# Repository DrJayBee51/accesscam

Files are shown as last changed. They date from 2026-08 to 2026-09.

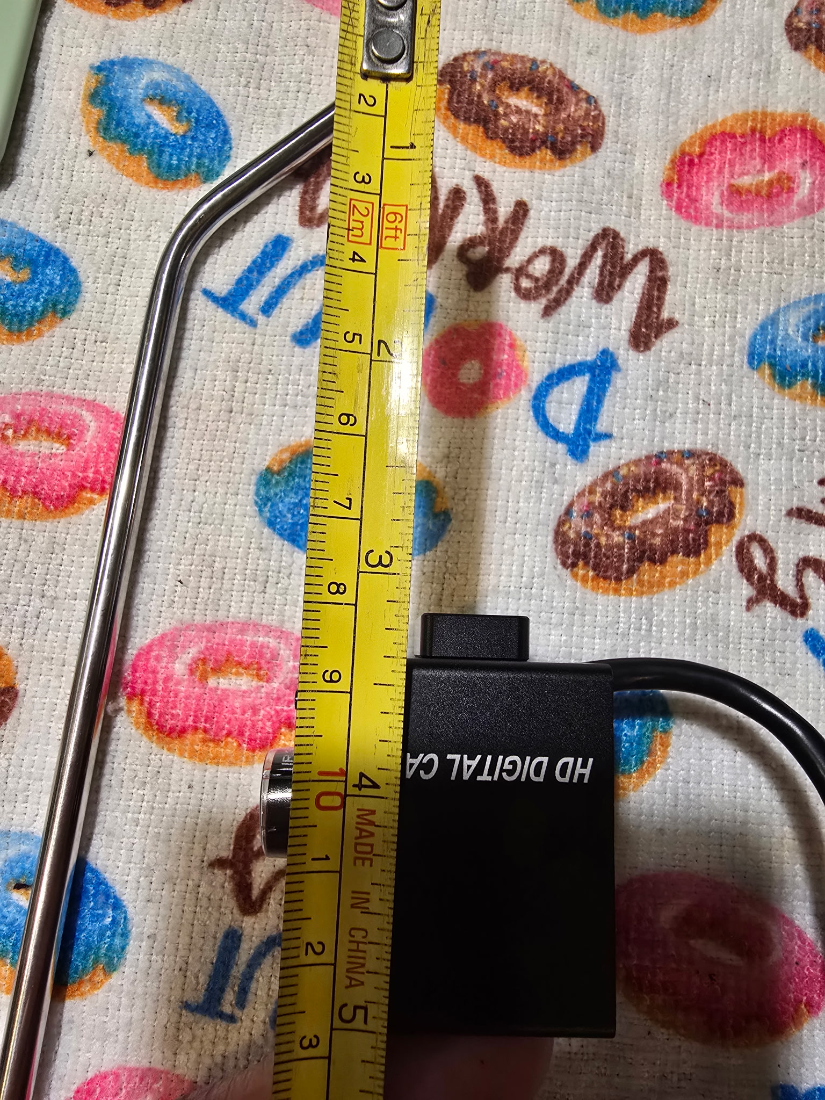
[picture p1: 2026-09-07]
hardware/MockCamera_ELP/20260813_200206.jpg.jpeg

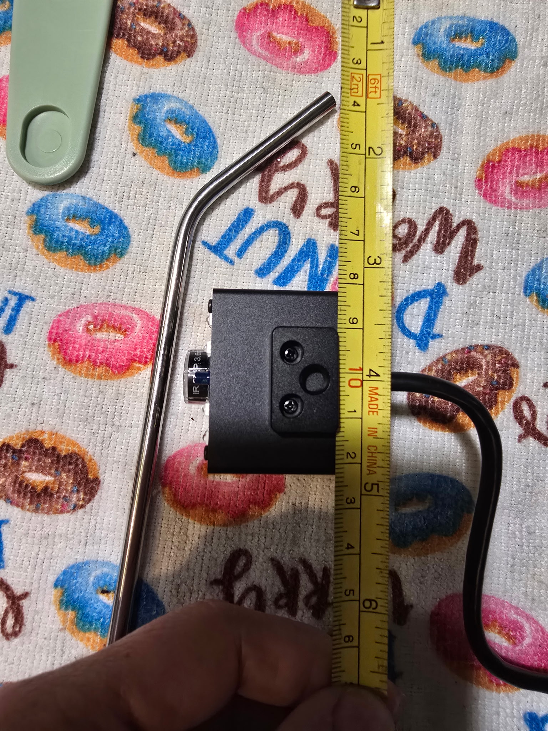
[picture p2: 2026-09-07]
hardware/MockCamera_ELP/20260813_200130.jpg.jpeg

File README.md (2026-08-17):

# AccessCam

**An open-source head-tracking mouse, built to replace the discontinued NaturalPoint SmartNav.**

AccessCam uses an off-the-shelf IR USB camera to track a retroreflective dot (worn on the forehead, glasses, or a hat brim) and translates head movement into mouse cursor movement — restoring the workflow that SmartNav users depend on, with hardware that can actually be purchased and repaired.

## Status

🚧 **Early development.** Windows support is being built first, followed by Linux, then macOS. See [docs/PROJECT_PLAN.md](docs/PROJECT_PLAN.md) for the roadmap.

**The cursor works.** There is no UI yet — you configure it with a JSON file
and control it with a pause hotkey. To get it running on a machine, follow
**[docs/RUNNING.md](docs/RUNNING.md)**.

```powershell
python -m accesscam --list-devices          # find the camera
python -m accesscam --device 1 --write-config
python -m accesscam --dry-run               # verify without moving the cursor
python -m accesscam                         # F9 to take control
```

## How it works

```
IR LEDs illuminate a retroreflective dot → camera sees it as the brightest
blob in frame → OpenCV finds its centroid each frame → motion is scaled by
user-tunable gains, filtered for noise, and applied to the system cursor.
```

## Planned v1 features

- Track a retroreflective dot with a UVC IR camera (tested with the Arducam 1080P Day/Night B0205)
- **Horizontal & vertical gain sliders** — tune cursor speed/distance independently per axis
- **Smoothing slider** — One Euro filter to suppress jitter without adding sluggish lag
- **Relative or absolute positioning** toggle
- **Pause/resume hotkey** — park the cursor when you need to
- **User profiles** — save and switch between named settings profiles
- System tray app with live camera preview for aiming and diagnostics

## Planned for later versions

- Dwell clicking (hover-to-click) with configurable dwell time and click type
- Calibration wizard
- Linux support, then macOS support

## Hardware

- **Camera:** Arducam 1080P Day & Night Vision USB camera (OV2710, 6× 850nm IR LEDs) or any UVC camera that can see 850nm IR. See [docs/HARDWARE.md](docs/HARDWARE.md) for important setup notes (the IR-cut photoresistor must be shrouded).
- **Marker:** a small dot of retroreflective material (3M Scotchlite 7610 tape or equivalent — the same material SmartNav dots were made from).
- **Mount:** a 3D-printable monitor mount/housing, designed in SolidWorks (files will live in `hardware/`).

## Development setup

```powershell
python -m venv .venv
.venv\Scripts\Activate.ps1
pip install -e ".[dev]"
pytest
ruff check . ; ruff format --check .
```

Run `pytest`, not `python -m pytest`. The `-m` form puts the working directory
on `sys.path`, so an import that only resolves from the repository root passes
locally and fails in CI, which runs it bare. That difference cost two days of
red builds on green local runs.

### Camera bring-up

Before there's a UI, `tools/camera_bringup.py` validates the hardware and tunes
tracking. It shows a live preview with the detected marker overlaid, and
measures the two numbers that set the app's defaults: how far the dot travels
across the sensor, and how much the tracked position jitters when you hold
still.

```powershell
python tools/camera_bringup.py --list      # find your camera's index
python tools/camera_bringup.py --device 0
```

Keys: `[` `]` adjust the brightness threshold, `-` `=` adjust exposure, `j`
measures jitter, `r` resets the travel range, `s` saves a snapshot, `q` quits
and prints a summary for the checklist in [docs/HARDWARE.md](docs/HARDWARE.md).

## License

[MIT](LICENSE)

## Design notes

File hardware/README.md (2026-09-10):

# Hardware

CAD files for the camera housing and monitor mount, organized **one folder per
part**, with the files named after the folder:

```
hardware/
  CameraHousing_Arducam/
    CameraHousing_Arducam.SLDPRT   (SolidWorks source)
    CameraHousing_Arducam.STL      (print-ready mesh)
    CameraHousing_Arducam.STEP     (neutral format for FreeCAD/Fusion users)
  CameraHousingAssembly_Arducam/
    CameraHousingAssembly_Arducam.SLDASM
  ...
```

## Naming — which camera a part belongs to

Every part and assembly carries its camera as a suffix, `_Arducam` or `_ELP`.
The two modules have different footprints and their own mount bases, so a bare
`MonitorMountBase` stopped being unambiguous the moment both existed.

| | Arducam (shipping) | ELP (evaluated alternative) |
| --- | --- | --- |
| Mock camera | `MockCamera_Arducam` | `MockCamera_ELP` |
| Housing | `CameraHousing_Arducam` | — |
| Mount base | `MonitorMountBase_Arducam` | `MonitorMountBase_ELP` |
| Assembly | `CameraHousingAssembly_Arducam` | `CameraHousingAssembly_ELP` |

Renamed 2026-09-07. Before that the Arducam parts carried no suffix and
`MockCamera_ELP` was `ELP_Camera` — worth knowing when reading commits from
before that date. Commits before 2026-09-10 also carry a second housing piece,
`CameraHousing2_Arducam` (`HousingBottom` before the rename); the one-piece
housing replaced it.

## Rules

Every **part** folder (a `.sldprt` source) must contain all three of:

1. the SolidWorks source file (`.sldprt`)
2. an `.stl` export (ready to slice)
3. a `.step` export (so contributors without SolidWorks can modify the design)

**Assembly** folders (a `.sldasm` source) need only the assembly file. An
assembly is a container of parts rather than something you print as a single
mesh, and each part it references already carries its own exports.

CI enforces this: `python tools/check_hardware.py` runs on every push and
fails if any part folder is incomplete. Run it locally before committing.

Name the files after the folder, and the folder after the part and its camera
(see *Naming* above). When you change a part, re-export **both** the STL and
STEP so they never drift out of sync with the SolidWorks source — the checker
only proves the exports exist, never that they are current.

## Export settings

**STEP: use AP214** (or AP242 if your SolidWorks version offers it — it's the
modern standard that merged AP203 and AP214, and FreeCAD 0.19+ and Fusion both
read it). AP214 preserves colors, materials, and assembly structure, which
plain AP203 does not. Set this once in Tools → Options → Export → STEP.

**STL: binary format, and keep the triangle count sane.** Deviation/angle
tolerance drives file size hard — a very fine export of a simple part can
produce 700k triangles and a 35 MB file. Git stores every revision of a binary
forever, so oversized meshes bloat the repo permanently. Aim for a few MB at
most; use the finest setting only for parts whose printed surface finish
actually depends on it (never for fit-check mockups).

See [../docs/HARDWARE.md](../docs/HARDWARE.md) for the design requirements the
housing must satisfy (photoresistor shroud, filter slot, aiming adjustment).

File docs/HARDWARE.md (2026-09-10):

# Hardware Notes

## Camera: Arducam 1080P Day & Night Vision USB (Amazon B0829HZ3Q7, module B0205)

| Spec | Value | Relevance |
|---|---|---|
| Sensor | 1/2.7" OV2710 CMOS | IR-sensitive with the IR-cut filter out of the path |
| Frame rates | MJPEG: 30fps at every resolution (640×480 → 1920×1080); YUY2 much slower | **Use MJPEG.** 640×480@30 is the sweet spot: full fps, least USB2 bandwidth/latency |
| Illumination | 6× 850nm IR LEDs | Lights up the retroreflective dot; driven by the same photoresistor circuit as the IR-cut switch |
| IR-cut filter | Mechanical, auto-switched by an onboard **photoresistor** | ⚠️ See below — must be forced to night mode |
| Lens | 105° F1.6 "starlight" | Wide FOV means fewer pixels per degree of head motion; crop/ROI in software if needed |
| Interface | USB 2.0 UVC | Driverless on Windows/Linux/macOS |

**This is the shipping default, decided 2026-08-18** — confirmed after months
of daily use rather than inherited by accident. It is sufficient for what
AccessCam does and outperforms any comparable platform on sale, so the
production housing is dimensioned around this module and the documentation
assumes it. An ELP module was modelled in `hardware/MockCamera_ELP/` and
evaluated as an alternative; it is kept for reference and is not chosen.

AccessCam itself stays camera-agnostic: it speaks UVC, and `--list-devices`
identifies a candidate by whether it grants 1920×1080. Any IR-capable UVC
camera will drive the cursor. What is specific to the Arducam is the *housing*
and the photoresistor shroud below, which is a property of this board rather
than of the software.

## ⚠️ Critical: force night mode

The board's photoresistor senses **ambient visible light**. In a normally lit
room the camera sits in *day* mode: the IR-cut filter blocks 850nm and the IR
LEDs are off — retroreflective tracking is impossible.

**The 3D-printed housing must cover the photoresistor** (a small light-tight
shroud or a blob of the enclosure over it) so the board always believes it is
dark: filter stays out of the light path, IR LEDs stay on. Verify before
finalizing the print: cover the photoresistor with a fingertip/tape and
confirm the LEDs glow faintly red and the image goes IR (room lights on).

## Housing / monitor mount — SolidWorks design requirements

1. **Photoresistor shroud** — light-tight cover over the photoresistor only;
   do not block the lens or the six IR LEDs.
2. **Monitor-top mount** — SmartNav-style perch: rests on the top bezel with a
   rear counterweight/clamp lip; fits bezels ~10–40mm deep.
3. **Tilt adjustment** — ±20° pitch so the camera can aim at the user's
   forehead from above the screen; friction hinge or notched detents.
4. **Filter slot (optional but recommended)** — a slot in front of the lens
   for an 850nm IR-pass filter (a cheap acrylic square, or the classic exposed
   film / floppy-disk-magnetic-media stopgap). Blocks visible light so the dot
   is nearly the only thing in frame.
5. **Ventilation + strain relief** — small vents; route the USB pigtail so it
   doesn't torque the board.
6. **Board mounting** — the module is a bare 38×38mm-class PCB (measure the
   actual board and hole spacing with calipers before modeling); standoffs for
   M2 screws or snap posts.

## Mount base provenance — why `MonitorMountBase_Arducam` is in inches

The original plan was to reuse the SmartNav's own monitor base. That was
dropped: **the SmartNav stays connected and working** as a fallback while
AccessCam is built (see the "user's daily driver breaks" risk in
PROJECT_PLAN.md), so its base can't be cannibalised.

`MonitorMountBase_Arducam` is therefore a replica, traced from the only
reference available — the original base's STL, which was authored in inches.
The part is consequently modelled in **inches** (2.000 × 1.550 × 1.400in =
50.80 × 39.37 × 35.56mm, 0.150in walls) while every other part in `hardware/`
is metric — including `MonitorMountBase_ELP`, whose STEP declares millimetres.

**This is intentional, not a units bug.** The geometry is physically correct
and its STEP declares `CONVERSION_BASED_UNIT('INCH')`, so FreeCAD/Fusion place
it at the right size. Don't "fix" it by rescaling — that would break the fit
against the real monitor. The production housing (M3) rebuilds this in MMGS.

## Development prototype vs. production housing

The current `CameraHousing_Arducam` / `MonitorMountBase_Arducam` pair is a
**bring-up prototype**, not the shipping design. The housing is one piece — a
second piece was carried until 2026-09-10, when a tang moulded into the housing
took over the job — and that tang slips into the mount base's channel on about
0.23mm of clearance per flank. The camera slots in from above and is held by
gravity — no fasteners, no captive retention, no tilt detents, and nothing
fastening the housing to the mount base. That is a deliberate trade: it gets a camera
pointed at the user quickly and lets the board be pulled out freely while
exposure, filtering, and aim are still being tuned. Requirements 2, 3 and 6
above are only partly met by it.

Do not print this for daily use. The production revision is scheduled as the
hardware track of **M3**, once development testing has settled the geometry.

## Windows capture backend

OpenCV offers two Windows backends and they do not behave the same. Measured
on a test camera (2026-08-08, OpenCV 5.0):

| Backend | Exposure control | Notes |
|---|---|---|
| `CAP_DSHOW` (DirectShow) | Full range — accepted −10 | Currently the default on Windows |
| `CAP_MSMF` (Media Foundation) | **Clamped** — requested −10, held at −6 | Also reports no usable FOURCC |

Short exposure is what makes the marker the only bright object in a lit room,
so a backend that clamps the range can make tracking impossible. The bring-up
tool displays both the requested and driver-reported exposure so clamping is
visible, and `--backend dshow|msmf` switches between them. Re-check this on
the Arducam — the behaviour is driver-specific, not universal.

### Confirmed on the Arducam (2026-08-09, OpenCV 5.0, Python 3.14)

The clamping above reproduces exactly: **MSMF holds at −6, DirectShow grants
−10.** So DirectShow stays the Windows default.

The Arducam enumerates as a generic **"USB Camera"** (`VID_0C45&PID_6366`).
With a second webcam attached it came up as **index 1**, so bring-up needs
`--device 1`; it is the only index granting 1920×1080, which is how to tell it
apart from a LifeCam-class device.

**FOURCC ordering gotcha — costs 2× the frame rate.** Setting `CAP_PROP_FOURCC`
*before* the frame size leaves this camera in uncompressed YUY2. Setting it
only *after* the size negotiates MJPEG. Setting it both before and after fails
the same way as before-only, so the first call is what poisons the negotiation:

| DirectShow call order | 640×480 | 1280×720 |
|---|---|---|
| FOURCC before size | YUY2, 14.8fps | YUY2, 10.0fps |
| **FOURCC after size** | **MJPG, 29.3fps** | **MJPG, 29.3fps** |
| FOURCC before *and* after | YUY2, 14.8fps | YUY2, 10.0fps |

`camera.py` sets it after the size for this reason. Exposure −10 is honoured in
every one of those orderings, so this is purely about frame rate.

MSMF reaches 30fps at 640×480 and even 1920×1080, which means it negotiates
MJPEG on its own — it just never reports a readable FOURCC. It remains
unusable here because of the −6 exposure clamp.

## Retroreflective marker

- Material: **3M Scotchlite 7610** high-gain reflective tape (this is what
  SmartNav dots were). eBay/Amazon sell small sheets cheaply.
- Punch 8–12mm dots with a hole punch. Backing: adhesive on forehead sticker,
  glasses frame, or hat brim — same spots SmartNav users already use.
- Spare SmartNav dots also work as-is.

## Validation checklist (M1 exit) — ✅ complete 2026-08-10

- [x] Camera enumerates as UVC on Windows; MJPEG 640×480@30 confirmed with a
      real fps counter (not the advertised number) — 29.3–29.5fps measured
- [x] Photoresistor shrouded → IR LEDs on and filter open with room lights on
- [x] Exposure can be driven low enough (via OpenCV `CAP_PROP_EXPOSURE`) that
      the dot is the brightest blob in frame in a daylight room — −9 in
      daylight, −7 at night, unclamped on DirectShow, headroom to −10
- [x] Dot tracked across the full comfortable head-motion range at seating
      distance; note the pixel span (this calibrates default gains) —
      **82.8 × 44.3px**
- [x] Jitter while holding still measured (pixel std-dev) — feeds smoothing
      defaults — **0.073 × 0.045px**

**A caveat on the travel figure.** It measures how far *the user moved*, not a
property of the camera, so it varies run to run and is not a constant to
hardcode. Three runs gave 68.7, 41.4 and 82.8px horizontally; the first two
were contaminated by the distractor-tracking bug described above. Treat 82.8 as
a starting point for default gains and expect per-user calibration to be
necessary — which is an argument for pulling the M5 calibration wizard forward.

**Shorter exposure improves precision, not just contrast.** Jitter fell 3–5×
between −7 and −9. The intensity-weighted centroid needs a brightness gradient
across the blob; a saturated marker is a plateau of 255s and the weighting
degenerates into a geometric centroid. Prefer the shortest exposure that still
holds the dot.

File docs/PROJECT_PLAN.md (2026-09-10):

# AccessCam Project Plan

## Goal

Replace a failing, discontinued NaturalPoint SmartNav 4 with an open-source
equivalent: an IR USB camera tracks a retroreflective dot worn by the user, and
a desktop application converts that motion into mouse cursor movement with
user-tunable gains, smoothing, and positioning mode.

*Named profiles were part of this sentence until 2026-08-15, written before
there was any usage to check it against. They moved to M5 — see there for why.*

Platform order: **Windows → Linux → macOS.**

## Decisions made (2026-08-08)

| Decision | Choice | Rationale |
|---|---|---|
| Stack | Python 3.11+ / OpenCV / NumPy / PySide6 | Fastest iteration; OpenCV blob tracking easily outruns the camera's 30fps; Qt gives a native cross-platform settings UI |
| v1 scope | Cursor movement only | User clicks by other means today; dwell click is v2 |
| License / visibility | MIT, public GitHub repo | Help other stranded SmartNav users; invite contributors |
| Camera (initial) | Arducam 1080P Day/Night USB (OV2710, 850nm IR LEDs) | Already owned; UVC so no drivers needed |
| **Camera (shipping default), 2026-08-18** | **The same Arducam B0205** | Confirmed rather than merely inherited, after months of daily use: it is sufficient for what AccessCam does and outperforms any comparable platform available today. The ELP model in `hardware/` was evaluated as an alternative and is not chosen. Anything UVC still works — this is the camera the housing is built around and the documentation assumes |

## Architecture

A processing pipeline running in a background thread, with a Qt UI observing it:

```
CameraSource ──► DotTracker ──► MotionMapper ──► Smoother ──► MouseBackend
 (capture        (find the      (px delta →      (One Euro     (move the
  thread,         brightest      cursor delta;    filter)       OS cursor)
  UVC controls)   blob           gains; relative/
                  centroid)      absolute)
                       │
                       ▼
                 Qt UI: live preview, sliders, tray icon
```

Planned module layout (`src/accesscam/`):

| Module | Responsibility |
|---|---|
| `camera.py` | Capture thread; enumerate devices; set resolution/fps/**exposure** via OpenCV/UVC; deliver frames |
| `tracker.py` | Threshold + contour/blob detection; return dot centroid (sub-pixel) and confidence; handle "dot lost" |
| `mapper.py` | Convert centroid motion to cursor motion. Relative mode: frame-to-frame delta × (H gain, V gain). Absolute mode: camera-space position → screen position through gains. Dead zone for micro-tremor |
| `smoothing.py` | One Euro filter (speed-adaptive: heavy smoothing when still, low lag when moving). The UI smoothing slider maps to its cutoff parameters |
| `engine.py` | Owns the pipeline and runs it on its own thread; publishes a status snapshot and the latest frame, and retunes live via `apply()`. Front ends observe it rather than containing it — a Qt event loop has to own the main thread, so the pipeline cannot |
| `mouse/` | Backend interface + `windows.py` (SendInput via ctypes). Later: `linux.py` (uinput/XTest), `macos.py` (Quartz) |
| `config.py` | Settings as flat JSON in the platform config dir (`%APPDATA%\AccessCam` on Windows); unknown keys ignored rather than fatal. Named profiles on top of this are M5 |
| `hotkeys.py` | Global pause/resume hotkey (essential — the cursor must be parkable) |
| `ui/` | PySide6: main window (preview + sliders + mode toggle), tray icon, first-run camera picker |

**Latency budget:** at 30fps a frame arrives every 33ms; processing must stay
trivially small next to that (blob detection on a thresholded frame is <1ms).
The dominant latency is the camera itself — which is why exposure should be
kept short and why a faster camera is the single best future upgrade.

## Milestones

### M0 — Project setup ✅ (2026-08-08)
Repo scaffolded, plan and hardware docs written, GitHub repo published.

### M1 — Tracking prototype (software) & mount (hardware) ✅ (2026-08-10)
The two tracks met as planned: real tracking could not be validated until the
camera was mounted and a reflective dot worn.

**Software:** ✅ `tools/camera_bringup.py` built — live preview, measured fps,
MJPEG/exposure control with clamp detection, threshold + sub-pixel blob
centroid overlay, and travel-range and jitter measurement.

**Bring-up runs:**

| Run | Light | fps | Exposure | Travel x/y (px) | Jitter x/y (px) |
|---|---|---|---|---|---|
| 2026-08-09 22:46 | lamplight | 29.3 | −7 | 68.7 / 48.1 | 0.208 / 0.195 |
| 2026-08-10 11:35 | daylight | 29.5 | −9 | 41.4 / 17.5 | 0.041 / 0.123 |
| 2026-08-10 12:2x | daylight | 28.8 | −9 | 1.2 / 3.2 | — |
| **2026-08-10 12:5x** | **daylight** | **29.3** | **−9** | **82.8 / 44.3** | **0.073 / 0.045** |

Read the last row as the trustworthy one. The two middle runs were corrupted by
a tracking bug, not by lighting: `_select` chose the largest blob on
acquisition, so a bright daylight object took the track and `max_jump` then
defended it, leaving the marker permanently ineligible. Travel collapsed toward
zero because the tracked object never moved. Fixed by filtering on shape and
ranking on brightness — see the commit and HARDWARE.md.

**Exposure matters twice over.** −9 was needed in daylight against −7 at night,
and the shorter exposure also *improved precision* 3–5×. The intensity-weighted
centroid needs a brightness gradient across the blob to work with; at longer
exposures the marker saturates into a plateau of 255s and the weighting
degenerates toward a plain geometric centroid. Default to the shortest exposure
that still holds the dot, not merely one that works.

**Effective resolution:** travel ÷ jitter gives ~1130 distinguishable
horizontal positions and ~980 vertical — 3–4× better than the first night's
figures, and enough to make relative-mode mapping comfortable. Horizontal and
vertical gains also came out within 5% of each other on this run, where earlier
runs disagreed by 60%; another sign the earlier travel figures were
contaminated rather than merely noisy.
**Hardware (SolidWorks):** monitor-top housing per `docs/HARDWARE.md` — must
shroud the IR-cut photoresistor, allow tilt aiming, and optionally hold an
IR-pass filter. Print, mount, and make a reflective dot (3M 7610 tape).
This first housing is deliberately a **development prototype**: the camera
slots in from above with no fasteners, so it can be pulled out and re-seated
freely during bring-up. `MonitorMountBase_Arducam` replicates the SmartNav
base (see HARDWARE.md → *Mount base provenance*). Good enough to test with;
not the shipping design.
**Exit criteria:** ✅ dot tracked at a steady ~30fps at normal seating distance,
in daylight and lamplight, with jitter measured. All met — 29.3–29.5fps across
every run, tracked under lamplight at −7 and daylight at −9 with no exposure
clamping, jitter measured in both.

### M2 — Cursor control engine ✅ (2026-08-15)
Mapper, One Euro smoothing, Windows SendInput backend, pause/resume hotkey,
config file (no UI yet — tune via config + hotkey reload).

**Relative mode is the priority; absolute is secondary.** The M1 travel figures
make this concrete. The target desktop is four 2560×1440 screens — 7680×3600
virtual — and 82.8px of dot travel has to cover it:

| Span | Gain | 0.073px jitter becomes |
|---|---|---|
| One screen (2560 wide) | 31 px/px | ~2px |
| Full desktop (7680 wide) | 93 px/px | ~7px |

**Verified against the real desktop (2026-08-10), DPI-aware.** 7680×3600 with
its origin at (−2560, −2160) is the true extent in *physical* pixels —
`GetSystemMetrics` returns the same values with and without per-monitor
awareness, so the gain figures above stand. An earlier draft of this section
claimed they were DPI-scaled and needed re-measuring; that was wrong.

The setup is nonetheless **mixed-DPI**, which is why awareness still matters:

| Display | Origin | Physical | Scale |
|---|---|---|---|
| DISPLAY1 (top) | (0, −2160) | 3840×2160 | 150% |
| DISPLAY3 (left) | (−2560, 0) | 2560×1440 | 100% |
| DISPLAY4 (primary) | (0, 0) | 2560×1440 | 100% |
| DISPLAY2 (right) | (2560, 0) | 2560×1440 | 100% |

A process that has not called `SetProcessDpiAwarenessContext` sees DISPLAY1 as
2560×1440, so it must be called before any metrics call.

At ~7px of cursor granularity across the full desktop, absolute mode is not
disqualified on resolution alone — an earlier draft of this section said it was,
based on the contaminated travel figures. What still argues against it is that
its mapping is fixed, so a miss stays missed, and that the four screens cover
only ~70% of the virtual bounding box: absolute mapping aims at coordinates
that may not be on any monitor, and Windows then snaps the cursor to the
nearest screen. Relative mode degrades gracefully instead —
overshoot, then re-center and take a second pass. This matches how the SmartNav
is used today, in relative mode for
exactly this reason. Build and tune relative first; treat absolute as a
best-effort mode, and expect it to need a screen-selection choice rather than a
naive map onto the whole virtual desktop.

**Multi-monitor moves here from M5.** With a 7680px-wide desktop the gain that
suits one screen is 3× off for the whole thing, so it is a correctness concern
for the mapper rather than a later convenience. At minimum, decide whether
gains map to one screen or the whole virtual desktop, and make it configurable.

**Progress (2026-08-10):** mouse backend ✅, mapper ✅, One Euro smoothing ✅,
pause hotkey ✅, config ✅, pipeline ✅. `python -m accesscam` drives the
cursor, and it is running on both the development and work machines.

Tuned by use rather than theory on first light: `h_gain` 100, `v_gain` 70,
`min_cutoff` 0.15, `beta` 0.4, `max_step` 2500. Three things came out of that
session — a `max_step` of 400 was truncating fast gestures so they travelled
less far than slow ones over the same ground, the cursor accumulated movement
into screen regions belonging to no monitor, and hover-driven UI needs
AccessCam run as administrator.

**Signed off (2026-08-15).** The exit criterion was a comfortable 15+ minutes of
real work; what actually happened was **four consecutive days of 8+ hours** on
the work PC, as the daily driver, across three screens. That is the criterion by
two orders of magnitude. Two problems came out of it, both now fixed:

- **A daylit office window rivalled the marker** and stole the track. Neither
  shape nor brightness filtering can reject a window, so blobs outside an opt-in
  region of interest are now excluded entirely.
- **Jitter at slow speeds was tiring over a full day**, and made holding a caret
  still for text selection hard. The smoother was already at its floor, so the
  fix had to be in the gain: it is now scaled down while the marker is nearly
  still. See *Holding the cursor still* in RUNNING.md.

Both were found by use and neither was predictable from the bench. The pattern
worth keeping for M3: ship the smallest thing that can be lived with, then live
with it for a week before deciding what is wrong.

**Per-machine settings have diverged** — different screen counts, different
lighting, different gains. Both machines' settings are recorded in RUNNING.md,
one block each.

This briefly looked like an argument for named profiles. It is not: `%APPDATA%`
is already per-machine, so the two installations never collide. What actually
hurts is carrying settings between a development PC and a work PC through a
*repository*, which is a build-workflow problem and does not exist for anyone
who installs the app once. See M5.

The hotkey is a bare **F9** rather than a modifier chord because the fallback
input when the cursor is unusable is a mouth-operated QuadStick with F9 already
mapped; a chord would not be reachable from it. `parse_hotkey` therefore
permits unmodified *function* keys while still rejecting bare letters and
digits, which a global hotkey would swallow system-wide. Verified with 8 of 8
physical presses: correct alternation, no key-repeat storms, clean unregister.

**AccessCam claims F9 globally while running**, so nothing else on the system
receives it. SmartNav had F9 mapped and was remapped to F6 to free it.

Two things cost a long debugging detour and are worth not rediscovering:

- **A rival low-level keyboard hook consumes the key without making
  registration fail.** SmartNav claimed F9 with a `WH_KEYBOARD_LL` hook rather
  than `RegisterHotKey`, so ours registered successfully and then received
  nothing. If a hotkey registers cleanly but never fires, suspect another
  application's hook, not the registration.
- **Software-injected keystrokes do not drive `RegisterHotKey`.** A hook saw a
  synthetic F9 arrive with `LLKHF_INJECTED` set while no `WM_HOTKEY` was
  delivered. `SendInput` cannot test this path; only physical presses can.

**Exit criteria:** daily-drivable cursor control from the tracked dot in
relative mode; the user can navigate their desktop comfortably for 15+ minutes,
including moving between monitors.

### M3 — Desktop UI and the production housing (parallel)
**Software:** PySide6 window: live preview with dot overlay, H/V gain sliders,
smoothing slider, acceleration controls, relative/absolute toggle, tray icon,
start-minimized and launch-at-login options.

**Progress (2026-08-16).** The pipeline moved out of `app.run` into
`engine.py`, which runs it on its own thread and publishes a status snapshot —
a Qt event loop has to own the main thread, so the pipeline could not stay
where it was. On top of that, all ✅:

- The three-tab window behind `--ui`, with live preview, a draggable region
  picker, the acceleration curve plotted live, and help behind question marks
- Tray icon that carries state — green driving, red parked — with closing the
  window hiding to it rather than quitting
- *Application* tab: camera selection with rescan, start-minimised, start at
  logon, and a confirmed Quit
- A **first-run camera picker** (2026-08-16). The picker in the Application tab
  sat behind a successful start, so a machine where the stored index is wrong —
  which is most machines on a first run, since `device` defaults to 0 and a
  built-in webcam habitually takes it — ended at "could not start" with no way
  past. Failing to open the camera now offers the list instead of exiting, and
  remembers the answer. Operable entirely from the keyboard, because the person
  meeting this dialog does not have a working pointer yet

**Launch-at-login is a scheduled task, not the usual registry Run key.**
AccessCam wants to be elevated (UIPI, see RUNNING.md) and a Run entry cannot
elevate, so `startup.py` registers `schtasks /rl highest /sc onlogon`. Creating
it needs admin, so the checkbox reports what is actually registered rather than
what was asked for. It targets `pythonw.exe` deliberately: `python.exe` is a
console application and would put a black box behind the window at every logon.

Still outstanding:

- **The relative/absolute toggle.** Lowest value of what is left — absolute is
  best-effort and needs a screen-selection decision before a toggle means much.
- **Ten settings unreachable** from the window: `backend`, `width`,
  `height`, `fps`, `max_jump`, `d_cutoff`, `invert_x`, `invert_y`, `dead_zone`,
  `max_step`. `invert_x`/`invert_y` are two cheap checkboxes and
  mount-dependent; the rest are advanced. **`hotkey` came off this list on
  2026-08-21** - it is a dropdown on the Application tab, pulled forward from
  M5 because editing JSON to change the one key that parks the cursor was a
  poor answer for the people this ships to.
- **Single-instance detection.** A second instance cannot open the camera and,
  launched by the logon task under `pythonw` with no console, dies without
  saying anything. Harmless at logon, but it needs handling before M4 ships to
  anyone else — either refuse politely or hand focus to the running instance.

**The exit criterion below needs rewording before it can be met.** It asks for
every setting to be adjustable, but the camera
settings cannot be live at all: changing `device`, `width`, `height` or `fps`
means closing and reopening the capture, which `Engine.apply` deliberately
refuses. "Every setting that can be changed without reopening the camera" is
the achievable version.

**No profile management here** — it moved to M5 on 2026-08-15. The single
settings file is enough for a machine with one user, which is every
installation that exists. See M5 for the reasoning and the design.

**Hardware (SolidWorks) — production housing.** Supersedes the M1 slot-in
prototype, now that development testing has settled the camera position, tilt
angle, and filter choice. Must add what the prototype deliberately skipped:

- Captive board mounting (M2 screws or snap posts) instead of the open slot
- A retention feature so the camera cannot fall out when the monitor is bumped
- Tilt adjustment that *holds* its setting — friction hinge or notched detents,
  ±20° pitch (HARDWARE.md req 3)
- Clamp or counterweight on `MonitorMountBase_Arducam` spanning the full
  10–40mm bezel range, plus a fastened interface to `CameraHousing_Arducam`
  (the prototype has neither; it is a fixed ~29mm perch that simply rests in
  place, and the housing's tang only slips into its channel)
- Strain relief for the USB pigtail, and vents
- Rebuild in **MMGS** — the prototype inherits inch units from the traced
  SmartNav base, but nothing downstream of it needs to

**Exit criteria:** all settings adjustable live and persisted; app runs from the
tray. Housing survives a day of normal use without drifting out of aim, and the
camera is captive.

### M4 — v1.0 release (Windows)
PyInstaller one-folder build, versioned GitHub Release, install/setup guide
with photos, printable STL + filter/dot instructions published in `hardware/`.

**Remaining work, itemised** (re-surveyed against the code 2026-08-18). Done
means the line after "Done:" is true, not that the work felt finished.

#### Blocking — the release is broken or unshippable without these

**M4.1 — Say in the window when it is not elevated.** ✅ *Done 2026-08-18.*
`warn_if_not_elevated()` is called once, at `app.py:127`, inside the *headless*
`run()`. The UI path only writes elevation to the log. A packaged app has no
console at all, so someone who double-clicks the exe gets an install where the
cursor moves but every hover-driven window ignores it — the failure that took
longest to attribute the first time anyone met it, and the one least likely to
be reported as a bug rather than abandoned.
*Done: the window says so unmissably while unelevated, and offers the fix.*

**M4.2 — Single-instance detection.** ✅ *Done 2026-08-18.* Nothing implements it (searched:
no mutex, no lock). A second copy waits `--wait-for-camera` seconds for a
camera the first copy holds, then blames the hardware in a dialog. Under the
logon task with `pythonw` it dies with no console at all. A named mutex is the
usual answer; the choice worth making is whether the second copy exits quietly
or hands focus to the first, and the latter is what a user double-clicking a
shortcut twice actually means.
*Done: launching twice surfaces the running instance and never accuses the camera.*

**M4.3 — The build.** ✅ *Done 2026-08-18.* `packaging/accesscam.spec`
produces a one-folder PyInstaller build (262MB unpacked) with a real Windows
version resource - the first attempt used `version_info={"version": ...}`,
which `EXE()` accepts silently and does nothing with, so the shipped exe had a
blank Properties > Details tab until this was caught and replaced with the
`VSVersionInfo` structure PyInstaller actually reads.

One folder rather than one file, deliberately: `--onefile` unpacks itself to a
temp directory on every launch, which costs seconds at exactly the moment
AccessCam is already racing the camera and the shell at logon, and leaves
antivirus software watching an executable materialise from nowhere at every
boot.

**The first build found a real bug**: `--ui` was never the default, so a
double-clicked `AccessCam.exe` opened *nothing* - no window, no tray - while
quietly taking over the pointer. `wants_ui()` in `app.py` now opens the window
whenever `sys.frozen` is set, unless `--headless` says otherwise; a source
checkout keeps the old default, since `python -m accesscam` is how the
pipeline gets exercised without a UI in the way. Verified from the built exe,
not from source: camera opened, window built, tray icon shown, hotkey
registered.

No release job in CI yet - left for whenever tagged releases start.
*Done: a one-folder build launches on a Windows machine that has never had
Python, opens the camera, and registers the logon task from the checkbox.*

**M4.4 — Decide the distribution shape.** ✅ *Decided 2026-08-18: an **Inno
Setup installer**.* It is the only shape that can satisfy M4.5, since a zip
leaves nothing behind to remove the logon task, and the people this is for are
often installing with someone's help — where "unpack it and find the exe" is
the step that goes wrong. Free, scriptable, and runnable in CI.

**The installed application does not require administrator rights**, and that
is deliberate rather than an oversight. AccessCam wants them, but demanding
them in the manifest would lock out anyone who is not an administrator of their
own machine — a real case in the schools and centres this is aimed at. It runs
as whoever launched it, says so in the window when that is not enough (M4.1),
and offers the scheduled task as the way up.

**M4.5 — Uninstall has to remove the logon task.** ✅ *Done 2026-08-18, built
into the same installer as M4.3/M4.4.* `packaging/AccessCam.iss` writes
`[Code]` rather than calling `startup.disable()` - the uninstaller is a
separate generated exe (`unins000.exe`) with no Python inside it, so the logic
is reimplemented directly in Pascal Script: try `schtasks /delete` unelevated
first, and only if the task survives that, prompt for elevation with
`ShellExec('runas', ...)` - the same on-demand-elevation pattern
`relaunch_elevated()` already uses, rather than requiring the whole
uninstaller to run as administrator. If both attempts fail, it says so and
gives the manual command rather than leaving a silent mess; a `MsgBox` at that
point is guarded by `UninstallSilent()`, since an unattended uninstall (an IT
deployment script, say) must never block on a dialog nobody is watching to
click.

Config and log in `%APPDATA%\AccessCam` are deliberately left alone -
`[UninstallDelete]` only targets the install directory. Settings tuned over
days of real use are not the installer's to discard.

**Verified end to end, with one deliberate exception.** Silent install and
uninstall were run against an isolated build with the task name swapped to a
throwaway value, confirming: the "no task registered" path exits cleanly with
no dialog (the common case - most users never enable logon start), the custom
Pascal code actually runs (confirmed via `Log()` lines in the Inno-generated
log, which does not capture custom `[Code]` by default), and no file outside
the install directory is touched. **Not verified**: actually deleting a
registered `/rl highest` task, because creating one to delete requires an
elevated shell, and this session had none to spare - test-registering even a
*non-elevated* task failed with Access Denied here, tighter than the
create-only restriction `startup.py` already documented. Deleting the one real
task on this machine to test against was ruled out: it is John's live logon
task, and there was no way to re-register it elevated afterward if the test
went wrong. Worth a five-minute real check next time the installer runs on a
machine with the task already set.
*Done: removing AccessCam leaves no scheduled task and no broken shortcuts.*

**M4.6 — Third-party licences.** ✅ *Done 2026-08-18.* `THIRD-PARTY-NOTICES.md`
covers what a build actually ships - PySide6/shiboken6 (LGPL-3.0-only, chosen
from Qt's dual/triple licence rather than GPL or commercial), OpenCV
(Apache-2.0 core, MIT wrapper), NumPy (BSD-3-Clause) - with the LGPL relinking
question answered rather than waved at: AccessCam's build is one-folder
specifically so Qt's DLLs sit beside `AccessCam.exe` as ordinary, unmodified,
replaceable shared libraries, which is exactly the "suitable shared library
mechanism" LGPLv3 §4(d)(1) describes as satisfying the licence without
requiring source to be conveyed. Worth knowing this reasoning connects back to
the M4.3 packaging-format decision, made for unrelated reasons, that happened
to make the licensing question easy to answer honestly.

The verbatim licence texts are vendored in `packaging/licenses/` - fetched
directly (not through a summarising tool) for the LGPL-3.0 text Qt's own wheel
does not include, and copied whole from the installed wheels for OpenCV and
NumPy rather than hand-curated, so a future third-party component either of
them bundles is not silently dropped. Both the frozen build (via the
PyInstaller spec) and the installer (via `AccessCam.iss`, at the install root
rather than buried under PyInstaller's `_internal\`, or the whole point is
defeated) ship the notices and every licence file.

A real gap turned up while wiring the build: the PyInstaller spec's artwork
list still named only two of the three tray states, two commits after the
third state was built - `tray-trouble.png` was never bundled, so a packaged
build would have silently fallen back to the drawn glyph for the one state
that matters most. Fixed by having the spec read the filenames from
`accesscam.ui.tray.TRAY_ART` itself rather than a second, driftable list.

`tools/check_licenses.py` (wired into CI as its own job) cross-checks
`pyproject.toml`'s declared runtime dependencies, each package's actual
installed licence metadata, and what `THIRD-PARTY-NOTICES.md` and
`packaging/licenses/` claim - catching a dependency added without a licence
entry, a vendored file going missing, or a package quietly relicensing between
versions, none of which a passing test suite would ever notice on its own.
*Done: a `THIRD-PARTY-NOTICES` file ships in the artifact, and the LGPL
relinking question is answered explicitly rather than ignored.*

#### Needed before anyone else is asked to install it

**M4.7 — Report a version.** ✅ *Done 2026-08-18.* `__version__ = "0.1.0"` exists in `__init__.py`
and is surfaced nowhere: no `--version`, no About. It is also duplicated in
`pyproject.toml`, so the two can disagree. A bug report against "AccessCam" with
no version is nearly useless.
*Done: one source of truth, reachable from both the command line and the window.*

**M4.8 — Code signing: SmartScreen, and the elevation problem it also solves.**
Reframed 2026-08-18 after looking at how the SmartNav actually does this, which
turned out to answer a question M4.1 and M4.4 had settled the hard way.

**The finding.** The SmartNav does not run as administrator. Its
`smartnav.exe.manifest` — an *external* manifest beside the exe, which is why a
search for an embedded one comes up empty — asks for:

```xml
<requestedExecutionLevel level="asInvoker" uiAccess="true"/>
```

`uiAccess="true"` is Windows' official accessibility exemption from UIPI. A
process holding it runs at ordinary privilege — no admin, no UAC prompt, works
for a user who is not an administrator of their own machine — and is still
allowed to deliver input to higher-integrity windows. It is precisely the
mechanism this application should be using, and what assistive technology is
*meant* to use.

Windows grants it only when all three hold, and the SmartNav satisfies all
three (verified on this machine 2026-08-18):

| Requirement | SmartNav |
|---|---|
| `uiAccess="true"` in the manifest | yes |
| Authenticode-signed by a trusted publisher | yes — GlobalSign, "NaturalPoint, Inc" |
| Installed under Program Files or System32 | yes — `C:\Program Files (x86)\NaturalPoint\` |

The signature and the protected location are the security argument: a standard
user cannot write to Program Files, so nobody can claim the exemption for a
binary they dropped on the desktop, and the certificate says who built it.

**Why this makes one certificate buy two things.** Signing was already on this
list to stop SmartScreen's "Windows protected your PC" on first launch. The
same certificate also unlocks UIAccess, which removes the elevation problem
outright: no administrator rights, no UAC prompt (unanswerable by a head-tracked
cursor, per M4.1), and no scheduled task needed *for elevation* — the task stays
useful only for starting at logon. It also dissolves the tension M4.4 recorded:
AccessCam would work for a non-admin user at a school or rehab centre without
anyone elevating anything, which `requireAdministrator` would have made
impossible.

**Already prepared, so the day a certificate exists this is a short job:**

- `packaging/accesscam.spec` takes `uac_uiaccess` from `ACCESSCAM_UIACCESS=1`,
  opt-in and off by default. It **has** to be opt-in: Windows does not launch a
  `uiAccess="true"` binary that fails the signing or location test in some
  degraded mode, it refuses to start it at all — "A referral was returned from
  the server", verified against an unsigned build. Unconditional would mean a
  build nobody can run until the certificate is bought.
- `mouse/windows.py` grew `has_uiaccess()` (reads `TokenUIAccess` from the
  process token) and `can_reach_privileged_windows()`, and the M4.1 banner asks
  the combined question. A signed, properly installed AccessCam holding UIAccess
  is not running as administrator and does not need to be, so telling that user
  to restart elevated would be crying wolf.

**Proven end to end on 2026-08-18, with a self-signed certificate.** Before
spending anything on a real one, the whole mechanism was tested: a self-signed
code-signing certificate, its root imported into `LocalMachine\Root`, the
UIAccess build signed with it, and the result installed to
`C:\Program Files\AccessCam-UIAccessTest\`. Launched **unelevated**, AccessCam
logged:

```
elevated: False   uiaccess: True
```

So Windows does not require a *commercially* trusted certificate — only one the
machine trusts. Three things follow:

- **The mechanism works for AccessCam specifically**, not just in principle. No
  admin rights, no UAC prompt, no scheduled task, and the M4.1 banner correctly
  stays hidden because `can_reach_privileged_windows()` sees UIAccess.
- **A certificate can be deferred without deferring the benefit on known
  machines.** Signing with a self-signed certificate trusted on John's own PCs
  would give him UIAccess today. It does nothing for anyone else - a stranger's
  machine would not trust it, so a distributed build still needs a real
  certificate - and it means trusting a self-signed root machine-wide, which is
  a real if small risk: anyone holding that private key could sign anything the
  machine would then trust.
- **The remaining unknown is only reputation and reach**, not capability. What a
  purchased certificate buys is SmartScreen (M4.8's original purpose) and the
  ability for *other people* to get UIAccess. It is no longer a question of
  whether the approach works.

**Still to decide, and both cost something:**

1. **The certificate itself.** Roughly $100–400/year for a standard OV
   certificate. An EV certificate clears SmartScreen immediately rather than
   after building reputation, and costs more.
2. **Install location.** UIAccess requires Program Files, but the installer is
   currently per-user (`PrivilegesRequired=lowest`) precisely so it needs no
   admin. A machine-wide install needs administrator rights **once, at install
   time** — the same trade the SmartNav makes, and a normal thing for IT to do —
   in exchange for never needing them again. Worth offering both: a per-user
   install that works unelevated without UIAccess, and a machine-wide one that
   gets it.

*Done: either signed — with UIAccess enabled and the install location decided —
or the SmartScreen warning documented at the point the user meets it.*

**M4.9 — The README is stale.** It still says "There is no UI yet — you
configure it with a JSON file", which is the front page of a repository whose
whole point by then is a downloadable application.
*Done: the front page describes what M4 actually ships.*

**M4.10 — Install and setup guide with photos.** `docs/RUNNING.md` is written
for someone with a clone, a venv and a terminal. The installing user has an
exe, a camera in a box, and a piece of reflective tape.
*Done: a guide that starts at "download this" and ends at a moving cursor.*

**M4.11 — Elevated with no steps after the install.** ✅ *Done 2026-09-07,
validated 2026-09-08.* M4.1 through M4.5 left elevation costing the user two
manual steps after every install — click "Restart as administrator", answer a
UAC prompt on the secure desktop, then find the Application tab and tick a box
— and the first of those is a dialog a head-tracked cursor cannot reach, so it
had to be done with the QuadStick or someone else's hand. Windows will not
grant the rights without an administrator decision somewhere; what could move
was *when*. The installer now registers the startup task at the end of the
install (ticked by default, elevating only that call), and an unelevated
AccessCam runs that task and quits in favour of the elevated copy it starts,
before it reads the config or opens the camera. Every route in — Start Menu,
desktop, taskbar pin, the exe — comes up elevated.
*Done: installed on the work PC on 2026-09-08 from an installer built at
`a9c2ee7`, and it worked. That machine is where AccessCam is the daily driver
and the SmartNav is not recognised, so it is the install that mattered.*

#### Known gaps that M4 consciously ships with

- ~~The hotkey can only be changed by editing JSON.~~ ✅ Done 2026-08-21:
  a dropdown of F1–F24 on the Application tab, which falls back to the previous
  key if the new one is already held by another program.
- **Eleven settings remain unreachable from the window** (M3 lists them).
- **Relative mode only**; absolute still needs a screen-selection decision.

#### The hardware half

**The camera is decided: the Arducam B0205, as of 2026-08-18.** It is
sufficient for what AccessCam does and outperforms any comparable platform on
sale, and it has months of daily use behind it rather than a spec sheet. The
ELP model stays in `hardware/` as an evaluated alternative, not a candidate.
That unblocks the production housing, which can now be dimensioned against one
camera instead of hedging between two.

What remains is the M3 production housing itself, which has not been started —
still the M1 slot-in prototype. M4 then needs the printable STL, the filter and
dot instructions, and the bezel range published alongside the software.

### M5 — v2 features
Dwell clicking (dwell time, click type, visual countdown), calibration wizard,
optional gravity/precision mode near targets. (Configurable hotkeys were pulled forward to M3 on 2026-08-21.) (Basic
multi-monitor handling moved up to M2 — see there. Note that the M2
acceleration curve may have already covered most of what a precision mode was
for, so re-examine that item before building it.)

#### Named profiles — deferred here from M3 (2026-08-15)

**Why they were deferred.** Profiles were in the goal statement from
2026-08-08, written before there was any usage to check them against. Three
things emerged once there was:

- **The user of the device this replaces never used the feature.** That is the
  best evidence available, and it outweighs speculation.
- **Per-machine settings need no profiles.** `%APPDATA%` is already per-machine,
  so two installations are separate by construction. The pain that made profiles
  look urgent was syncing a *repository* between a development PC and a work PC:
  a build-workflow problem, not a product one.
- **Profiles have no user until M4 ships.** Their justification is shared
  institutional machines, and no institution can install this before there is
  an installer.

**Why they are not cancelled.** The testing centre at the user's college ran
SmartNav on a **single shared desktop login**, which is the one case Windows
user accounts do not already solve. Rehab centres and assessment stations are
the same shape. Real, but institutional, and worth building when an institution
asks rather than in anticipation.

**The constraint that case imposes — this is the part worth not rediscovering.**
At a testing centre a proctor sets up for someone who cannot use the mouse yet.
A profile picker operated *with the cursor* is therefore useless to the person
who needs it: selecting the profile requires the working cursor that selecting
the profile is meant to provide. Profile selection has to happen at **launch**,
not inside the settings window — a `--profile` flag, a per-user desktop shortcut
a proctor configures once, or a first-screen picker reachable from the keyboard
or a QuadStick. Same single-key-reachable reasoning that made the pause hotkey a
bare F9.

**Storage design, already worked out.** A profile is just a named config file,
so this is a naming and selection layer rather than a new schema — `Config.load`
and `Config.save` already take an optional path:

```
%APPDATA%\AccessCam\
  config.json              <- untouched; unchanged behaviour when no profiles exist
  active.json              <- {"profile": "work"}
  profiles\<name>.json
```

Resolution order, first match wins:
`--config PATH` → `--profile NAME` → `active.json` → `config.json` → defaults.

Purely additive, with no automatic migration: silently rewriting the config of a
tool someone depends on for computer access is a bad trade against the risk in
the table below. Opting in means running `--save-profile` once.

Keep profiles **flat** — every key in every file, identical to `Config` — and
document `device` as the one value to fix when copying between machines. The
alternative, splitting machine-level keys into their own file, invents a second
schema and a merge step to solve one integer.

Profile names become filenames, so validate them: `[A-Za-z0-9_-]`, 1–64
characters, and reject the Windows reserved device names (`con`, `prn`, `aux`,
`nul`, `com1`–`com9`, `lpt1`–`lpt9`) case-insensitively. `con` passes a naive
character check and then fails at `open()` in a way that is hard to diagnose.

### M6 — Linux port
`uinput`-based mouse backend (evdev), packaging (AppImage or Flatpak),
Wayland/X11 notes. UVC camera and OpenCV already work there.

### M7 — macOS port
Quartz event mouse backend, camera permission handling, notarized .app bundle.

## Risks & mitigations

| Risk | Impact | Mitigation |
|---|---|---|
| 30fps camera ceiling (OV2710) | Less smooth than SmartNav's ~100Hz | One Euro filter tuned per-user; run at 640×480 MJPEG for lowest latency; document upgrade path (Arducam OV9281 global-shutter, 120fps, ~$40 — software is camera-agnostic via UVC) |
| Auto IR-cut engages in lit rooms, blocking IR | Tracking dies in daylight | Housing shrouds the photoresistor to force night mode (see HARDWARE.md) |
| Bright room objects (windows, lamps) rival the dot | False tracking | Short exposure + optional 850nm IR-pass filter; blob size/shape filtering; track nearest-to-last-position |
| Python 3.14 wheel availability (OpenCV/PySide6) | Setup friction | Pin to Python 3.12 in the venv if 3.14 wheels lag; `requires-python >=3.11` keeps options open |
| The user's daily driver breaks while the SmartNav degrades | Lost computer access | Keep milestones small; M2 already yields a usable fallback device |

## Out of scope (for now)

Eye/gaze tracking, face-feature tracking without a marker (OpenTrack/eviacam
territory), game head-look (TrackIR protocol), mobile/iOS.

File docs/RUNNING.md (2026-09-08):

# Running AccessCam

How to get the cursor moving on a machine that has never run it. Written for
Windows, which is the only platform with a mouse backend so far.

## What you need

- The Arducam and its printed housing, mounted on top of a monitor and plugged
  into **this** machine's USB
- A retroreflective dot on your forehead, glasses, or hat brim
- Python 3.11 or newer

## 1. Install

```powershell
git clone https://github.com/DrJayBee51/accesscam.git
cd accesscam
python -m venv .venv
.venv\Scripts\Activate.ps1
pip install -e .
```

## 2. Find the camera

The index differs from machine to machine, and a built-in webcam often takes 0.

```powershell
python -m accesscam --list-devices
```

The Arducam is the one that grants **1920x1080**; lower-resolution webcams will
not. Then save it:

```powershell
python -m accesscam --device 1 --write-config
```

That writes `%APPDATA%\AccessCam\config.json`, which you can edit by hand
afterwards — every value is in there, and anything you leave out falls back to
its default.

## 3. Check the shroud before anything else

Cover the photoresistor on the camera board and confirm the **IR LEDs glow
faintly red** with the room lights on. If they do not, the board is in day
mode, the IR-cut filter is blocking 850nm, and no amount of software tuning
will make tracking work. See [HARDWARE.md](HARDWARE.md).

## 4. Dry run

```powershell
python -m accesscam --dry-run
```

This runs the entire pipeline but never touches the real cursor. You want to
see:

- `640x480 MJPG` — if it says anything else the frame rate will suffer
- `29-30fps` — the camera's real ceiling
- `tracking` and `lost 0%` — the marker is being found
- `pause hotkey: F9` registered

If `lost` is high, the marker is not being seen: check the shroud, and try a
shorter exposure with `--exposure -10`.

## 5. Run it as administrator

Not optional if you use an on-screen keyboard, or anything else that reacts to
the pointer hovering.

Windows' UIPI stops a normal-privilege process delivering input to a
higher-privilege one. The cursor still moves — the cursor is global — but the
target window never receives the mouse messages, so **hover-driven UI silently
stops responding**. Confirmed against Comfort On-Screen Keyboard Pro: keys do
not highlight under AccessCam unelevated, and highlight immediately when it is
launched from an Administrator terminal. UAC prompts and applications running
as administrator behave the same way.

AccessCam prints a note at startup when it is not elevated, and the settings
window carries a standing banner, so this is visible rather than a mystery.

**If you installed AccessCam, this is already done.** Setup offers to register
the startup task — ticked by default, and the one moment the whole design asks
for administrator rights. After that AccessCam hands over to an elevated copy
of itself whenever it finds it is not one, so the Start Menu entry, the desktop
icon, a taskbar pin and the exe itself all come up elevated with nothing asked
of you. Skip to step 6.

From a source checkout there is no installer, so spend that one prompt by hand.
Open PowerShell **as Administrator**, then:

```powershell
cd <wherever you cloned it>
.venv\Scripts\accesscam.exe --register-task
```

That registers a scheduled task running with highest privileges at logon —
equivalent to the command below, except that AccessCam composes it, so the
task and the app can never disagree about what should be running:

```powershell
schtasks /create /tn AccessCam /rl highest /sc onlogon /f `
  /tr "<path>\.venv\Scripts\accesscam.exe --ui --wait-for-camera 60"
```

From then on `.venv\Scripts\accesscam.exe` started any way at all will notice
it is unelevated, start the task, and quit in favour of the copy that comes
up. Pass **`--no-elevate`** when you want the unelevated copy you actually
asked for — testing the banner, or working on the pipeline itself.

### Starting it elevated on demand, without a UAC prompt

The task is not only for logon. `schtasks /run /tn AccessCam` starts it
elevated at any time and asks nobody — creating the task needed administrator
rights once; running it never does.

**AccessCam now does this to itself.** Before it reads the config, opens the
camera or claims the single-instance lock, an unelevated copy that finds a
registered task pointing at its own executable runs that task and quits. That
is why there is no separate "start elevated" shortcut any more: there is
nothing to start any other way. Two guards keep it honest — a task pointing at
some *other* copy is left alone rather than launching a build you did not ask
for, and a second handover within 90 seconds is refused, so a task registered
without `/rl highest` produces one wasted relaunch and a line in the log rather
than an invisible loop.

That matters more here than convenience. A process cannot elevate itself once
it is running, so every other route to administrator goes through a UAC prompt
on the secure desktop — which a head-tracked cursor cannot reach, because
AccessCam is not elevated at that moment by definition. Anyone who needs this
application to move their pointer would be stranded at a dialog they cannot
click. The scheduled task is the only route that never asks.

`tools/launch-elevated.vbs` is that one line, plus a message box if the task is
missing rather than a silent no-op. Make a shortcut to it:

```powershell
$repo = "<path to the repo>"
$shell = New-Object -ComObject WScript.Shell
$lnk = $shell.CreateShortcut([IO.Path]::Combine(
    [Environment]::GetFolderPath('Programs'), 'AccessCam.lnk'))
$lnk.TargetPath = "$env:SystemRoot\System32\wscript.exe"
$lnk.Arguments = "`"$repo\tools\launch-elevated.vbs`""
$lnk.IconLocation = "$repo\assets\accesscam.ico,0"
$lnk.Save()
```

Then pin it to the taskbar or the Start menu. `wscript` rather than a shortcut
straight to `schtasks.exe` only so that no console window flashes up.

If Windows Script Host is disabled by policy — plausible on a managed work
machine — point the shortcut at `schtasks.exe` with arguments
`/run /tn AccessCam` instead and accept the flash.

`assets/accesscam.ico` is generated from the same glyph the tray draws, so the
two cannot drift apart: `python tools/make_icon.py assets/accesscam.ico`.

## If the camera number is wrong

With `--ui`, AccessCam does not give up when it cannot open the camera in the
config: it scans for what is connected and offers the list, with the IR camera
marked as the one granting 1920×1080. Choose it and the answer is saved, so the
dialog appears once. The list is fully keyboard-operable — arrows and Enter —
since anyone meeting it does not have a working pointer yet.

Headless (`python -m accesscam` with no `--ui`) still exits, deliberately:
there is a console right there, and `--list-devices` answers the same question
without a window.

## 6. First light

```powershell
python -m accesscam
```

It **starts paused**. Press **F9** to take control, F9 again to park the
cursor. Ctrl+C in the terminal quits.

Expect to want a different gain immediately. Edit `h_gain` and `v_gain` in the
config: higher means the cursor travels further for the same head movement.
The defaults of 31 and 32 are calibrated for one 2560x1440 screen.

## Known-good settings, per machine

The config lives in `%APPDATA%\AccessCam\config.json` and is **not** in the
repository, so it does not travel with a clone. Recorded here instead, one block
per machine, because the two installations have diverged enough that a single
"starting point" is now misleading: they differ in screen count, in room
lighting, and therefore in gain.

There is deliberately no profile feature to switch between these. `%APPDATA%` is
already per-machine, so each installation keeps its own settings without help;
what this section solves is carrying them between machines through the
repository, which is a development concern rather than something a user of an
installed app ever meets. Named profiles are an M5 item for shared institutional
machines — see PROJECT_PLAN.md.

### Development PC — four screens, 7680×3600

Tuned 2026-08-10, retuned 2026-08-15 when pointer acceleration landed:

```json
{
  "device": 1,
  "exposure": -9,
  "threshold": 200,
  "h_gain": 120.0,
  "v_gain": 90.0,
  "min_cutoff": 0.15,
  "beta": 0.4,
  "max_step": 2500.0,
  "accel_floor": 0.35,
  "accel_knee": 25.0,
  "accel_sharpness": 3.0,
  "hotkey": "f9"
}
```

The gains went **up** — 100→120 and 70→90 — in the same change that added the
curve, and that is the point rather than a coincidence: damping the gain at rest
bought enough precision to afford a faster pointer everywhere else. Tuning them
apart from the curve would have found neither.

No region of interest is set here; the whole frame is searched.

### Work PC — three screens, 2560×1440 each

The daily driver, and where four days of full-day use surfaced the jitter
problem the curve fixes. A region of interest is set here because a daylit
office window rivalled the marker.

Verbatim from that machine's `config.json` on 2026-08-16, after its first
tuning session on the M3 build:

```json
{
  "accel_floor": 0.4,
  "accel_knee": 25.0,
  "accel_sharpness": 3.5,
  "backend": "dshow",
  "beta": 0.3,
  "clutch": 0.0,
  "d_cutoff": 1.0,
  "dead_zone": 0.0,
  "device": 1,
  "exposure": -9,
  "fps": 30,
  "h_gain": 105.0,
  "height": 480,
  "hotkey": "f9",
  "invert_x": true,
  "invert_y": false,
  "max_area": 5000.0,
  "max_jump": 120.0,
  "max_step": 2500.0,
  "min_area": 4.0,
  "min_circularity": 0.5,
  "min_cutoff": 0.3,
  "roi_h": 233,
  "roi_w": 268,
  "roi_x": 257,
  "roi_y": 237,
  "start_minimized": false,
  "threshold": 200,
  "v_gain": 80.0,
  "width": 640
}
```

**The curve bought room for faster gains here too.** 85/60 before it, 105/80
after — the same trade the development PC made, on a different screen count and
a different mount distance, which is the open question from the M2 notes
answered. The floor settled slightly higher (0.4 against 0.35) and the knee
matches at 25.

`min_cutoff` is 0.3 rather than the development PC's 0.15. Slow movement is
where the difference shows: below about 0.3 the resting jitter stops improving
while lag keeps growing, and on this machine that lag was noticeable when
placing the pointer on an on-screen keyboard key.

### Notes that apply to both

Anything omitted falls back to its default, so each block above is a complete
file as it stands.

- **`device` will differ.** Run `--list-devices` on each machine.
- **The gains depend on how far the camera sits from your head**, since they are
  calibrated against how far the marker travels across the sensor. If the mount
  geometry matches they should carry over; if the cursor feels wrong in the
  first minute, gain is the thing to change.
- **A region of interest changes the gains.** The box shrinks how much of the
  frame your head crosses, so gains tuned before setting one feel faster after.
- **`v_gain` lower than `h_gain` is deliberate** — vertical head movement has
  less comfortable range than horizontal, so it needs less amplification per
  pixel to cover its axis.

## The settings window

```powershell
.venv\Scripts\accesscam.exe --ui
```

Two tabs. **Camera & Marker** is everything that changes what the tracker sees —
exposure, threshold, the blob filters, and the region searched, which is set by
dragging the corner handles on the preview. **Cursor Movement** is everything
downstream of finding the dot — the gains, the acceleration curve, smoothing and
the clutch. Every change applies to the live cursor immediately; nothing needs a
restart to be felt.

Each setting has a `?` beside it. They open on click rather than on hover,
because a head-tracked pointer never stops moving and a hover tooltip would
disappear before it could be read.

Nothing in the window needs a drag. Every value has step buttons worth one click
each and steps with the arrow keys once focused; the slider is there for when
the pointer is cooperating. The one exception is the region box, and its
handles have a grab radius considerably larger than they are drawn.

**It lives in the tray.** The icon is green while the cursor is being driven and
red while it is parked, so the state is visible with the window closed. Closing
the window hides it there rather than quitting — ending cursor control with a
stray click on a title bar is a worse outcome than a window you have to reopen.
Quit is in the tray menu, along with **Start minimised**, which opens straight
to the tray on the next run.

Settings are not saved until you press **Save settings**. **Revert to saved**
puts back whatever is in the file, which is the way out of a session of tuning
that went nowhere.

## Safety

The cursor is driven with no window to click on, so **F9 is the way out**. It
is a bare function key rather than a chord specifically so it is reachable from
a QuadStick or similar fallback device. Keep a fallback input available the
first few times you run this.

If the cursor becomes unusable and F9 does not respond, Ctrl+C in the terminal
stops the program, and closing the terminal window kills it outright.

## Tuning

| Symptom | Setting | Direction |
|---|---|---|
| Cursor too slow / too fast | `h_gain`, `v_gain` | up / down |
| Want to re-bias your head at an edge | `clutch` | up from 0, try 600 |
| Cursor shimmers at rest | `min_cutoff` | down (calmer, more lag) |
| Fast movement feels delayed | `beta` | up |
| Marker lost in a bright room | `exposure` | down to -10 |
| Something else gets tracked | `threshold` | up toward 255 |
| Cursor jumps to a bright object | `max_area` | down |
| A daylit window keeps stealing it | `roi_*` | draw a box around yourself |
| Cannot hold still to select text | `accel_floor` | down from 1.0, try 0.35 |
| Long sweeps feel sluggish | `accel_knee` | down from 40 |

Shorter exposure improves precision as well as contrast: the sub-pixel centroid
needs a brightness gradient across the blob, and a saturated marker is a flat
plateau. Prefer the shortest exposure that still holds the dot.

## Holding the cursor still (pointer acceleration)

Four days of full-day use at work surfaced one problem the smoother cannot fix:
about 4px of wander remains at rest, and a flat gain multiplies all of it. That
is tiring over hours and it makes selecting text hard, because a caret has to be
placed precisely and then held.

`accel_floor` scales the gain down while the marker is nearly still and restores
it as you move, so precision and reach stop competing for one number:

```json
{
  "accel_floor": 0.35,
  "accel_knee": 40.0,
  "accel_sharpness": 1.8
}
```

- **`accel_floor`** — fraction of full gain used at rest. `1.0` is the default
  and disables the curve entirely, so the mapper behaves exactly as it did
  before. `0.35` cuts the resting wander to roughly a third.
- **`accel_knee`** — marker speed, in camera px/s, at which the gain has climbed
  halfway back. Below it you are positioning; above it you are travelling.
- **`accel_sharpness`** — how abruptly the gain climbs through the knee. Most
  setups never need to move it.

**A config written before acceleration existed has it off**, and silently: the
key is simply absent, absent keys take their defaults, and this default is the
one that disables the curve. So an installation that predates this section keeps
behaving exactly as it did until `accel_floor` is added by hand — which is the
right way round for a tool someone relies on, but it does mean nothing announces
the feature. Add the key to try it.

The scale is taken from the speed of the whole 2D movement and applied to
`h_gain` and `v_gain` together, so your existing calibration keeps its ratio and
a diagonal is never bent. The curve only ever reduces gain, so a fast sweep still
reaches as far as it does today.

Tune it in this order — each step depends on the one before:

1. **Move `accel_floor` alone** until you can place and hold a caret. This is
   the parameter that fixes the fatigue.
2. **Then check a long sweep** across every screen. If it drags, lower
   `accel_knee` — you are still in the slow region during real travel.
3. **Only then touch `accel_sharpness`**, up if the transition feels mushy, down
   if the cursor lurches as it picks up speed.

Give any setting a full working day before judging it. This was found over four
days, not four minutes, and a curve that feels strange for ten minutes is often
the right one.

### Expect to notice it, and then to stop

**What it feels like on the first day, measured 2026-08-17** on a full workday
at `accel_floor` 0.35: the reduced gain is noticeable *while typing* — small
head movements between keystrokes move the cursor less than they used to, and
the pointer feels heavy starting out of rest. After **15–20 minutes it stops
being noticeable at all**, and the same session was described as feeling like
the SmartNav it replaces.

Two things follow from that, and they matter more than the numbers:

- **Do not judge the curve in the first ten minutes**, and do not turn it off
  because the pointer feels heavy while you type. That sensation is the price
  being paid, and it is refunded by the end of the first coffee.
- **Re-tuning restarts the clock.** Adaptation is a one-off cost you have
  already paid; changing `accel_floor` again asks for it a second time. Worth
  it for a real problem, not for a tweak.

If the heaviness *out of rest* is what bothers you rather than the resting
precision, lower `accel_knee` rather than raising the floor: full gain then
returns sooner once you actually start moving, leaving the precision at rest
intact.

## When something bright keeps stealing the track

A window in daylight images as bright as the marker, and neither the shape nor
the brightness filter can reject it — a window is neither dim nor elongated. No
exposure or threshold will separate them either, because the offender is as
bright as the thing you are looking for.

Exclude it by area instead. Only blobs whose centre falls inside the region of
interest are considered, so a box drawn around yourself removes anything at the
frame edges:

```json
{
  "roi_x": 257,
  "roi_y": 237,
  "roi_w": 268,
  "roi_h": 233
}
```

All four at `0` — the default — searches the whole frame. `roi_w` or `roi_h` of
`0` counts as disabled rather than as a box that rejects everything.

Two things to know before relying on it. The box is fixed **in the camera
frame**, not to you: move your chair and you can leave it, and tracking then
stops entirely rather than degrading. That is a worse failure than a stolen
track, which is why it is off unless you ask for it. And the box shrinks how
much of the frame your head crosses, so gains tuned before setting one will
feel faster afterwards.

Pick the box visually rather than guessing pixels — see below.

## Tuning against the live preview

`tools/camera_bringup.py` is the M1 bring-up tool, and it stays useful long
after bring-up: it shows the camera with the tracked blob outlined, so you can
watch what the tracker is actually choosing while you change settings. It never
touches the cursor.

```powershell
.venv\Scripts\python.exe tools\camera_bringup.py --device 1
```

The HUD reports fps, exposure, threshold, the marker's position, area and
brightness — or `dot NOT FOUND` — plus travel range and the current box.

| Key | Effect |
|---|---|
| drag | draw a region of interest; outside it dims |
| `c` | clear the region of interest |
| `w` | write exposure, threshold and the box to the config |
| `[` / `]` | lower / raise `threshold` |
| `-` / `=` | shorten / lengthen `exposure` |
| `j` | measure jitter — hold still for a couple of seconds |
| `r` | reset the travel-range measurement |
| `s` | save a snapshot to `bringup/` |
| `a` | toggle auto exposure, for comparison only |
| `q` | quit and print a summary |

`w` loads the existing config before writing, so gains, smoothing and
everything else it does not tune survive untouched. Note the keys go to the
preview window, not the terminal — click it first.

Travel range is worth watching while you are in here: it accumulates only while
the marker is found, so a figure that stays near zero means the track is sitting
on something stationary rather than on you.

## When it does not start at logon

Read the log first. It is at:

```
%APPDATA%\AccessCam\accesscam.log
```

Every run appends to it, and this is the only place a logon start can speak
from: registered against `pythonw` there is no console, `print` goes nowhere,
and an unhandled exception disappears with the process. A healthy start looks
like this, and stops at whichever line it could not get past:

```
--- starting: --ui --wait-for-camera 60
elevated: True
creating the cursor backend
Qt is up
camera 1 opened on attempt 4 after 3.2s
window built
tray icon shown
pause hotkey 'f9' registered
running
```

`camera 1 opened on attempt 4` is worth watching. Attempt 1 means the camera
was ready before AccessCam asked; a high number means the USB enumeration race
is real on this machine and `--wait-for-camera` is what is covering it.

**`LastTaskResult` tells you whether the task even fired**, which separates a
scheduling problem from an application one in one command:

```powershell
Get-ScheduledTaskInfo -TaskName AccessCam
```

A `LastRunTime` matching the logon with `LastTaskResult = 1` means the trigger
worked and the app died — go to the log. Note that 1 is Python's exit code for
*any* unhandled exception, so it names nothing on its own.

The Task Scheduler's own Operational log is disabled by default and is worth
turning on before chasing a scheduling problem (Administrator):

```powershell
wevtutil sl Microsoft-Windows-TaskScheduler/Operational /e:true
```

## Sharing the cursor with a mouse

When something else moves the cursor — someone picking up the real mouse to
show you something — head tracking stands aside and picks up from wherever they
left it. On by default:

```json
{
  "yield_to_mouse": true,
  "yield_delay": 0.0
}
```

- **`yield_to_mouse`** — whether to give way at all. Off restores the old
  behaviour, where both devices drive the cursor at once and the head tracker
  wins by sheer frame rate, which makes the mouse feel broken rather than the
  tracker feel polite.
- **`yield_delay`** — how long to stay out of the way *after* the other device
  stops, in seconds, 0 to 1. Zero hands control back on the very next frame,
  so the pause lasts exactly as long as somebody is actually moving the mouse.
  Raise it if the cursor snatches control back while someone is using the mouse
  in short bursts.

It notices any device that moves the cursor, not just a mouse — detection is by
watching where the cursor actually is, not by inspecting mouse events. AccessCam's
own movement never counts, which is the part that makes this workable at all,
since AccessCam is itself moving the cursor thirty times a second.

A QuadStick counts only in the modes where it drives the cursor. The mode used
alongside head tracking sends keystrokes rather than pointer movement, so it
does not trigger this.

## Changing the pause hotkey

*Application* tab, **Pause hotkey**. F1 through F24.

Only function keys are offered, and that is not a simplification. A global
hotkey is swallowed system-wide while AccessCam runs, so claiming a letter would
remove it from all typing everywhere; and the key has to work as a single press,
because the fallback input when the cursor is unusable cannot readily produce
chords.

**F13–F24 are worth knowing about.** Almost no keyboard has them, which makes
them ideal here: nothing else is likely to be holding one, and an assistive
device can be mapped to send it.

If another program already holds the key you pick, the change is refused and the
previous key stays registered — AccessCam says which one is still in use rather
than leaving you with no way to park the cursor. A chord such as `ctrl+alt+p`
is still legal in the config file by hand; the dropdown leaves it alone and says
where the value came from.

## If the camera is unplugged

Nothing to do — AccessCam notices frames have stopped, closes the dead handle
and reopens the camera when it comes back, which takes a second or two. It looks
for the configured index first and then the others, because USB does not promise
the same number twice and a camera that returns as device 2 while the config says
1 would otherwise look like a hardware fault.

The tray icon shows the trouble state while frames are missing, so a camera that
is genuinely gone is visible rather than silent.

## Known gotchas

**F9 is claimed globally while AccessCam runs.** Nothing else on the system
receives it. If another application needs F9, change `hotkey` in the config —
any function key works unmodified, and chords like `ctrl+alt+p` are accepted
too.

**A rival low-level keyboard hook will silently eat the hotkey.** SmartNav's
software claims F9 that way. The registration still succeeds, so the only
symptom is a hotkey that never fires. If that happens, remap the other
application or pick a different key.

**Injected keystrokes do not trigger the hotkey.** Any script that tries to
test it with `SendInput` will report failure regardless. Only a real press
counts.

**AccessCam forces manual exposure, and the camera driver remembers it.** That
is deliberate — auto-exposure brightens the whole scene until room objects rival
the marker, and tracking dies. It is stored by the *driver* rather than by
AccessCam, so it outlives the process: a camera left at exposure −10 looks black
to every other application until something sets it back.

AccessCam now hands a camera back its auto-exposure whenever it is finished with
one — on quit, and when you switch to a different camera — so only the camera
actually being tracked with is left on manual. If you have an older AccessCam, or
a camera that was darkened before this existed, this restores it:

```powershell
python -c "import cv2; c=cv2.VideoCapture(0, cv2.CAP_DSHOW); c.set(cv2.CAP_PROP_AUTO_EXPOSURE, 0.75); c.release()"
```

Change the `0` to whichever device index is dark.

**The camera must be on the machine running AccessCam.** If a monitor is shared
between machines through a switch, the USB connection has to follow.

**At logon, AccessCam can start before the desktop is finished.** The trigger
fires within a second of the logon notification, and at that moment the camera
may still be enumerating and Explorer may not have created the notification
area yet. Both are waited for, for `--wait-for-camera` seconds, rather than
being asked about once — which is why the tray icon sometimes appears a few
seconds after the desktop rather than with it.

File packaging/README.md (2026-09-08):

# Building AccessCam

Two stages, run in order: PyInstaller freezes the Python application into a
folder, then Inno Setup wraps that folder into an installer. Neither is part
of the normal `pytest` / `ruff` loop - only run this when you actually need an
installable artifact.

```powershell
pip install -e ".[dev]"
pyinstaller packaging\accesscam.spec --noconfirm
```

That produces `dist\AccessCam\` - a one-folder build, `AccessCam.exe` plus
everything Qt and OpenCV need beside it. **Run it before going further**:
launch `dist\AccessCam\AccessCam.exe` directly and confirm the window opens,
the camera is found, and the tray icon appears. A build that doesn't do this
isn't worth wrapping in an installer.

Then, with [Inno Setup 6](https://jrsoftware.org/isdl.php) installed:

```powershell
& "$env:LOCALAPPDATA\Programs\Inno Setup 6\ISCC.exe" packaging\AccessCam.iss
```

(Or wherever ISCC.exe landed - a machine-wide install puts it under
`C:\Program Files (x86)\Inno Setup 6\` instead.) That produces
`dist\installer\AccessCam-Setup-<version>.exe`.

## What the installer does, briefly

Per-user install (`{autopf}` under `PrivilegesRequired=lowest`), so installing
needs no administrator rights. Desktop and Start Menu shortcuts, both pointing
straight at `AccessCam.exe`.

One task on the wizard's "Additional tasks" page, **ticked by default**, is the
exception: *Always run AccessCam with administrator rights*. It runs
`AccessCam.exe --register-task` at `ssPostInstall` - plainly first, since a
machine-wide install is already elevated, then through `ShellExec('runas', ...)`
if that fails, which is the single UAC prompt the design spends on purpose. The
app registers its own task rather than this script composing a `schtasks`
command line, so that what the task runs is defined once; a second definition
would drift, and `startup.state()` would start reporting a perfectly good task
as stale because the quoting differed.

After that AccessCam hands over to its own elevated copy whenever it finds
itself unelevated (`startup.take_over_elevated`), so every route in - shortcut,
pin, or the exe itself - ends up elevated with nothing more asked. Declining
the task leaves a working unelevated install, with the window's banner (M4.1)
and the Application tab offering the same registration later.

`tools/launch-elevated.vbs` is still installed as an escape hatch for a machine
where that handover does not work, though nothing shortcuts to it now.

Uninstall removes the logon task if one is registered - see the `[Code]`
section in `AccessCam.iss` and the M4.5 writeup in `docs/PROJECT_PLAN.md` for
why that's hand-written Pascal Script rather than a call into `startup.py`
(the uninstaller has no Python inside it). Config and log in
`%APPDATA%\AccessCam` are never touched by install or uninstall.

## UIAccess (not enabled yet — needs a certificate)

AccessCam needs to deliver input to higher-integrity windows (on-screen
keyboards, anything elevated), and today does it by running as administrator.
The better mechanism is **UIAccess**, Windows' accessibility exemption from
UIPI — the same one the SmartNav uses, via an external `smartnav.exe.manifest`
carrying `level="asInvoker" uiAccess="true"`. A process holding UIAccess needs
no admin rights and raises no UAC prompt.

The spec supports it already, opt-in:

```powershell
$env:ACCESSCAM_UIACCESS = "1"
pyinstaller packaging\accesscam.spec --noconfirm
```

**Do not set this until the exe is both signed and installed under Program
Files.** Windows grants UIAccess only to an Authenticode-signed binary in a
location standard users cannot write to. Fail either test and the process does
not start in a degraded mode — it does not start at all:

```
Start-Process : This command cannot be run due to the error:
A referral was returned from the server.
```

That is what an unsigned UIAccess build looks like, and it is why the flag is
off by default rather than always on. See `docs/PROJECT_PLAN.md` M4.8 for the
certificate and install-location decisions this waits on.

## Testing a change to the installer without touching the real logon task

`AccessCam.iss` matches the scheduled task by name (`AccessCam`), the same
name the real app's own "start at logon" checkbox registers. Compiling and
running the *real* script's uninstaller against a scratch install will still
try to remove whatever "AccessCam" task actually exists on the machine - which
on a development box is very possibly the one you rely on daily, and which
this session had no elevated shell available to re-register if that went
wrong.

To test uninstall logic safely, copy the script and change the task name and
output paths before compiling, so it operates on a name nothing else uses:

```powershell
Copy-Item packaging\AccessCam.iss packaging\AccessCamTest.iss
# edit the copy: TaskName = 'AccessCamUninstallTest'; different OutputDir
& ISCC.exe packaging\AccessCamTest.iss
# install and uninstall silently against that build, then delete the copy
```

Silent install/uninstall, useful for exactly this:

```powershell
Start-Process AccessCam-Setup.exe -ArgumentList '/VERYSILENT','/SUPPRESSMSGBOXES','/DIR=<path>','/LOG=<path>' -Wait
Start-Process <installdir>\unins000.exe -ArgumentList '/VERYSILENT','/SUPPRESSMSGBOXES','/LOG=<path>' -Wait
```

`/DIR=` and `/LOG=` both need a location the *current, unelevated* user can
actually write to - `C:\` root fails silently with exit code 1 and no log,
which looks identical to a genuine setup failure. Use `%LOCALAPPDATA%` or
`%TEMP%`.

The custom `[Code]` logic logs through Inno's own `Log()` procedure, which
lands in whatever file `/LOG=` points at - Inno's default logging does not
capture custom `[Code]`, so without those `Log()` calls a silent test run
looks identical whether the logon-task removal ran or was skipped entirely.

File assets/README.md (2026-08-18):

# Artwork

Drop files in here and AccessCam uses them. Nothing needs rebuilding or
registering: the loader looks for these names at startup and falls back to the
drawn ring-and-dot when a file is missing or unreadable, so half-finished
artwork is a safe state to leave the repository in.

| File | Where it appears | Notes |
|---|---|---|
| `accesscam.ico` | Desktop, Start menu, taskbar, Alt-Tab, the window's title bar, the installer | Multi-size `.ico` |
| `tray-active.png` | Notification area, **while the cursor is being driven** | Square PNG, transparent |
| `tray-paused.png` | Notification area, **while the cursor is parked** | Square PNG, transparent |
| `tray-trouble.png` | Notification area, **while something is wrong** | Square PNG, transparent |

## The three states

The design these were specified against: a head-and-shoulders silhouette, with
the marker on the face.

| State | What it means | The idea |
|---|---|---|
| Active | AccessCam has the pointer and can see you | Silhouette **with** the marker |
| Parked | Running, but not driving the cursor — F9 to take it | Silhouette **without** the marker |
| Trouble | Running, but something is stopping it working — a dead camera, or a hotkey that would not register | Silhouette with a **red X** |

The three differ in *what is drawn*, not only in colour, which is the point —
see below.

**What counts as trouble**, decided in `src/accesscam/health.py`:

- **No frames from the camera** for 3 seconds. Unplugged, driver fallen over,
  or another application has taken it.
- **The pause hotkey would not register**, which is permanent for the session
  and means the cursor cannot be parked from the keyboard.

**A missing marker is not trouble**, and that is worth stating because it looks
like the obvious candidate. Losing it is ordinary: you leave the desk to eat and
come back to a tracker that picks up where it left off, exactly as the SmartNav
does. AccessCam does nothing when the marker goes - the cursor stops where it
is, and the first frame after reacquisition is deliberately a zero movement so
it cannot jump - so there is nothing to report. Flagging it would have painted
the tray red through every lunch break. The window says whether the marker is
currently visible, and the tray tooltip mentions it, for anyone actually asking.

Slow to complain and quick to forgive: a condition has to persist before it is
shown, and clears the instant it goes away. An indicator that cries wolf gets
ignored on the one occasion it is right. The tooltip carries which of the three
it is and what to do about it.

## What the tray icon has to do

It is not decoration. Once the window is hidden the tray icon is the only thing
saying whether AccessCam currently has the pointer, and "is this thing on" is
the question a head-tracking mouse raises most often. So the two states have to
be **distinguishable at 16 pixels, at a glance, without moving the cursor over
it** — reading a tooltip requires the pointer, which is exactly what is in
question when the answer matters.

Three constraints worth designing against rather than discovering:

1. **16px is the real size.** Windows shows the notification area at 16px at
   100% scaling, 20–24px at higher. A 2px line is one pixel after rounding, and
   fine detail turns to grey mush. Draw it at 16 and scale *up*, not the other
   way round.
2. **It sits on both a dark and a light taskbar**, depending on the user's
   Windows theme, and you cannot detect which from a static file. The current
   drawn glyph fails this: its near-white ring nearly vanishes on a light
   taskbar. A shape that reads on both — or a dark outline around a light
   shape — survives either.
3. **Do not carry the state on colour alone.** Green against red is the least
   legible pair for the commonest form of colour blindness, and this is an
   accessibility tool. The marker present / absent / struck through does the
   work by itself, and colour reinforces it — which is why the specified design
   works: printed in greyscale, the three are still three.

## Sizes

`accesscam.ico` should contain 16, 24, 32, 48, 64, 128 and 256px images, each
drawn rather than downsampled, for the same reason as above. If your tool only
exports one size, export a 256px PNG and say so — converting it is a minute's
work and better done once, here, than by every viewer.

Tray PNGs: 32px or 64px square is plenty. Qt scales them down for the tray.

## Editable sources

Keep the working file (`.xcf`, `.psd`, whatever the tool produces) alongside
its exported `.png`, the same way `hardware/` keeps a `.SLDPRT` beside its
STL and STEP. Someone tweaking one state later should not have to redraw the
other two from scratch to match.

## The fallback

`tools/make_icon.py` regenerates `accesscam.ico` from the glyph drawn in
`src/accesscam/ui/tray.py`. Now that real artwork is in place it **refuses to
overwrite an existing file** and needs `--force` to do so — the GIMP source it
would discard is not something the script can rebuild from. It exists so a checkout without artwork still has an icon
of its own rather than a generic interpreter icon.

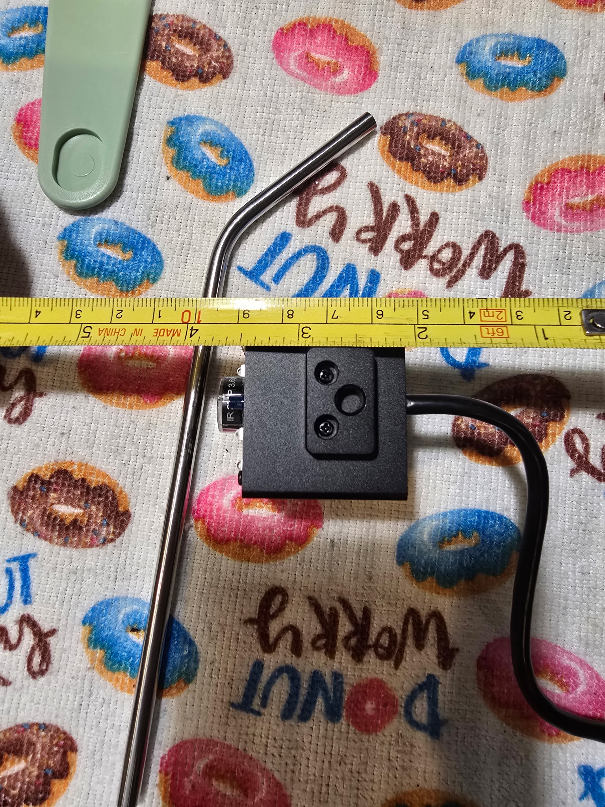
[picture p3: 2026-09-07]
hardware/MockCamera_ELP/20260813_200141.jpg.jpeg

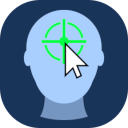
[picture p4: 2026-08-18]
assets/ico_xcfs/128x128.png

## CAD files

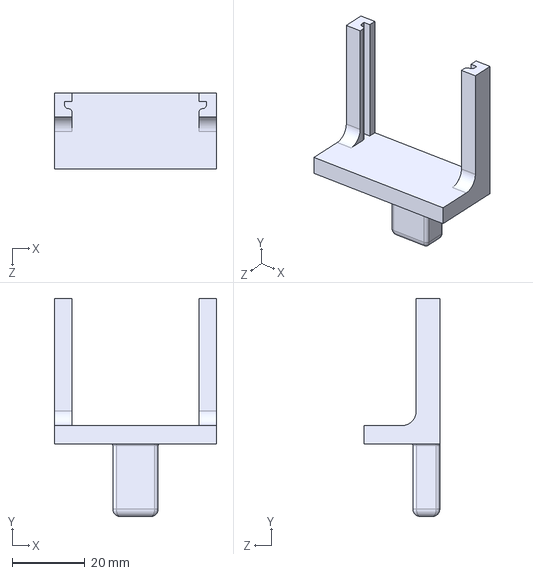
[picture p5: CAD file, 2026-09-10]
hardware/CameraHousing_Arducam/CameraHousing_Arducam.STEP
44.6 x 60.0 x 20.8 mm

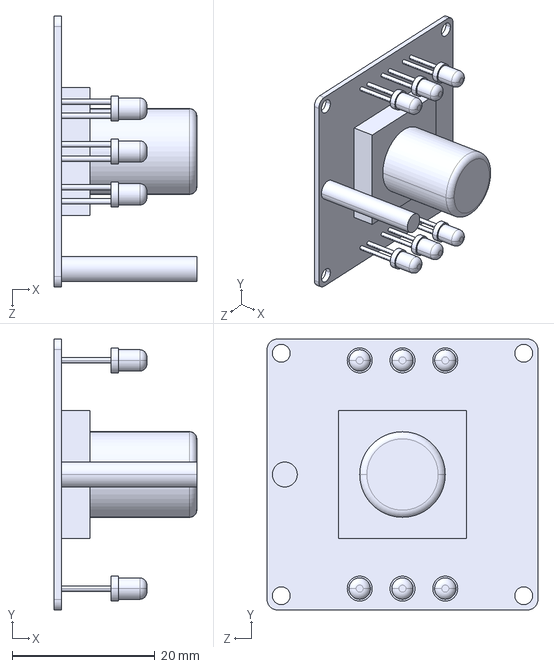
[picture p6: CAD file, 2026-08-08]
hardware/MockCamera_Arducam/MockCamera_Arducam.STEP
20.0 x 38.0 x 38.0 mm

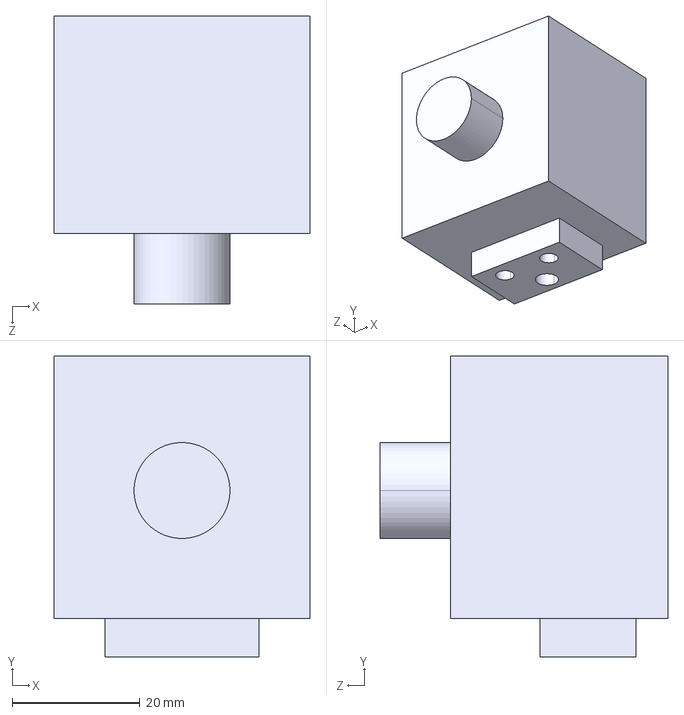
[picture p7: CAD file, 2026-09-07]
hardware/MockCamera_ELP/MockCamera_ELP.STEP
40.0 x 47.0 x 45.0 mm

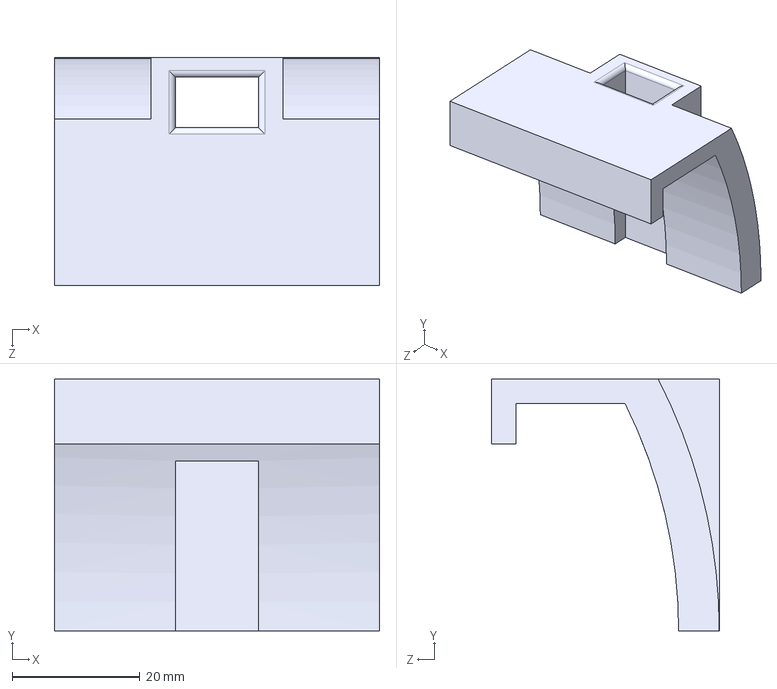
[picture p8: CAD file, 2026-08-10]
hardware/MonitorMountBase_Arducam/MonitorMountBase_Arducam.STEP
50.8 x 39.4 x 35.6 mm

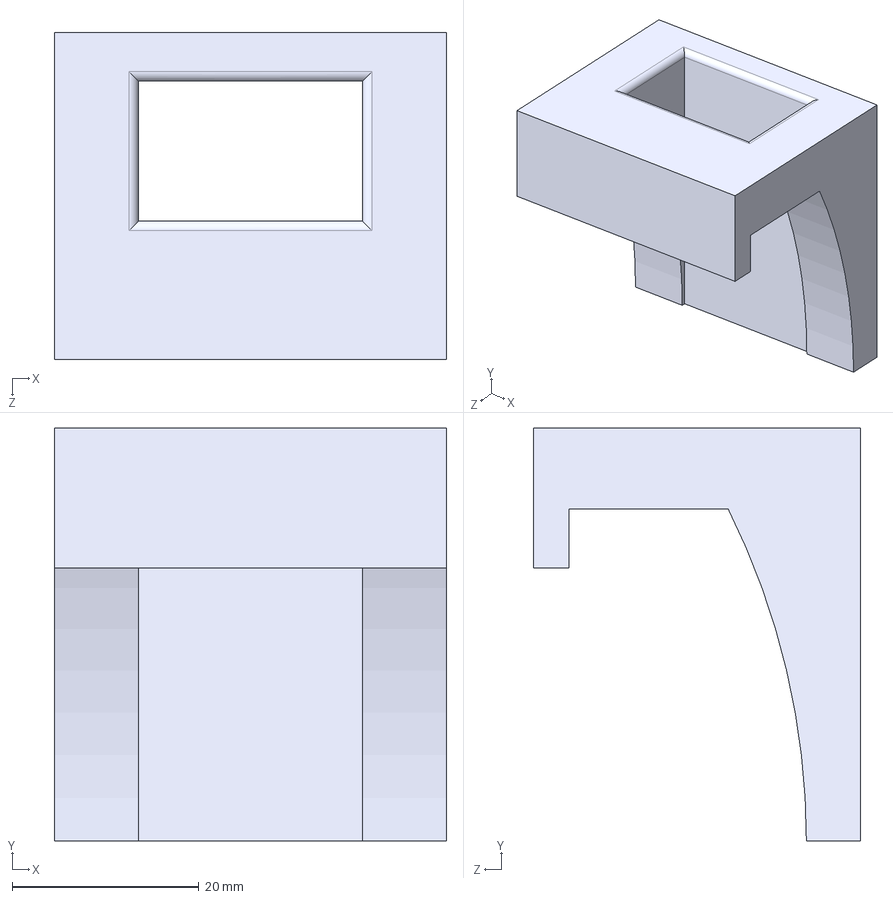
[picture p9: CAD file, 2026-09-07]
hardware/MonitorMountBase_ELP/MonitorMountBase_ELP.STEP
42.0 x 44.2 x 35.0 mm

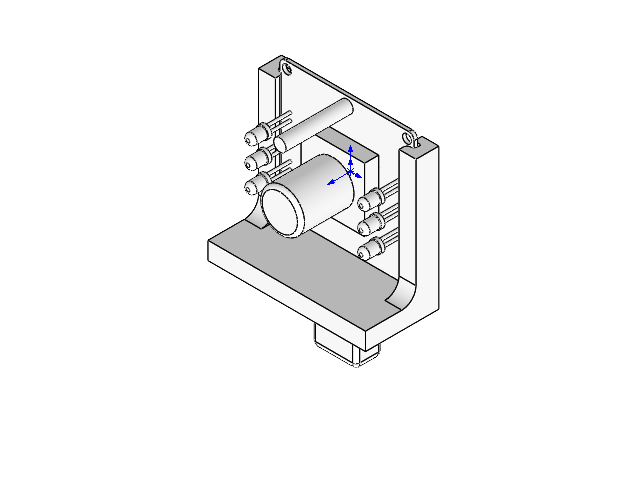
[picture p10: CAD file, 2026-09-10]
hardware/CameraHousingAssembly_Arducam/CameraHousingAssembly_Arducam.SLDASM
MockCamera_Arducam
CameraHousing_Arducam

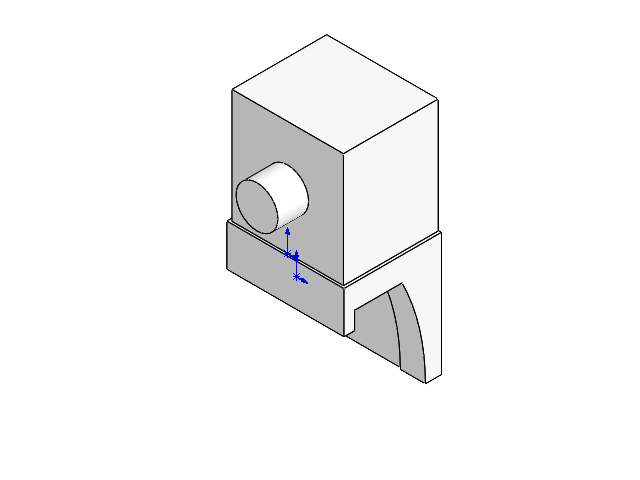
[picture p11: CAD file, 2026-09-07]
hardware/CameraHousingAssembly_ELP/CameraHousingAssembly_ELP.SLDASM
MonitorMountBase_ELP
MockCamera_ELP

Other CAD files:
hardware/CameraHousing_Arducam/CameraHousing_Arducam.SLDPRT
hardware/CameraHousing_Arducam/CameraHousing_Arducam.STL
hardware/MockCamera_Arducam/MockCamera_Arducam.SLDPRT
hardware/MockCamera_Arducam/MockCamera_Arducam.STL
hardware/MockCamera_ELP/MockCamera_ELP.SLDPRT
hardware/MockCamera_ELP/MockCamera_ELP.STL
hardware/MonitorMountBase_Arducam/MonitorMountBase_Arducam.SLDPRT
hardware/MonitorMountBase_Arducam/MonitorMountBase_Arducam.STL
hardware/MonitorMountBase_ELP/MonitorMountBase_ELP.SLDPRT
hardware/MonitorMountBase_ELP/MonitorMountBase_ELP.STL

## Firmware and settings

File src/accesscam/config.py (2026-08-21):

"""User configuration, stored as JSON in the platform's config directory.

Every default here is sourced from the module that owns it, so there is one
place to change any given value rather than two that can drift.

Unknown keys are reported and ignored rather than being an error: a config
written by a later version should not stop an earlier one from starting, and
being locked out by your own settings file is a bad failure for a tool someone
relies on to use their computer.
"""

from __future__ import annotations

import json
import os
import sys
from dataclasses import asdict, dataclass, fields
from pathlib import Path

from accesscam.hotkeys import DEFAULT_HOTKEY
from accesscam.mapper import (
    DEFAULT_ACCEL_FLOOR,
    DEFAULT_ACCEL_KNEE,
    DEFAULT_ACCEL_SHARPNESS,
    DEFAULT_H_GAIN,
    DEFAULT_MAX_STEP,
    DEFAULT_V_GAIN,
)
from accesscam.mouse.base import DEFAULT_CLUTCH
from accesscam.smoothing import DEFAULT_BETA, DEFAULT_D_CUTOFF, DEFAULT_MIN_CUTOFF
from accesscam.tracker import (
    DEFAULT_MAX_AREA,
    DEFAULT_MAX_JUMP,
    DEFAULT_MIN_AREA,
    DEFAULT_MIN_CIRCULARITY,
    DEFAULT_THRESHOLD,
)

APP_NAME = "AccessCam"


def config_dir() -> Path:
    if sys.platform == "win32":
        base = os.environ.get("APPDATA")
        return Path(base) / APP_NAME if base else Path.home() / "AppData" / "Roaming" / APP_NAME
    xdg = os.environ.get("XDG_CONFIG_HOME")
    return Path(xdg) / "accesscam" if xdg else Path.home() / ".config" / "accesscam"


def config_path() -> Path:
    return config_dir() / "config.json"


@dataclass
class Config:
    """Everything tunable, in one flat file the user can edit by hand."""

    # Camera
    device: int = 0
    backend: str = "dshow"
    width: int = 640
    height: int = 480
    fps: int = 30
    # Short exposure is what isolates the marker. -9 suited a bright room; -7
    # suited lamplight. Shorter also sharpens the sub-pixel centroid, so prefer
    # the shortest value that still holds the dot.
    exposure: int = -9

    # Tracking
    threshold: int = DEFAULT_THRESHOLD
    min_area: float = DEFAULT_MIN_AREA
    max_area: float = DEFAULT_MAX_AREA
    max_jump: float = DEFAULT_MAX_JUMP
    min_circularity: float = DEFAULT_MIN_CIRCULARITY
    # Region of interest, in frame pixels. Only blobs whose centre falls inside
    # this box are considered, which excludes fixed bright objects at the frame
    # edges (daylit windows, a lamp) that would otherwise rival the marker.
    #
    # There is no disabled state: the region is always in force, and a zero
    # width or height means "the whole frame" rather than "off". One always-live
    # box that is sometimes the size of the frame is easier to reason about than
    # a feature that silently is or is not applied - and it means the preview
    # always has a box to show and drag, instead of one appearing from nowhere.
    roi_x: int = 0
    roi_y: int = 0
    roi_w: int = 0
    roi_h: int = 0

    # Smoothing
    min_cutoff: float = DEFAULT_MIN_CUTOFF
    beta: float = DEFAULT_BETA
    d_cutoff: float = DEFAULT_D_CUTOFF

    # Mapping
    h_gain: float = DEFAULT_H_GAIN
    v_gain: float = DEFAULT_V_GAIN
    invert_x: bool = True
    invert_y: bool = False
    dead_zone: float = 0.0
    max_step: float = DEFAULT_MAX_STEP
    # Pointer acceleration, off until accel_floor drops below 1.0. The floor is
    # the fraction of full gain used while the marker is still: 0.35 cuts the
    # resting wander to roughly a third, which is what makes holding a caret
    # still for text selection workable. Tune it before touching the other two.
    accel_floor: float = DEFAULT_ACCEL_FLOOR
    accel_knee: float = DEFAULT_ACCEL_KNEE
    accel_sharpness: float = DEFAULT_ACCEL_SHARPNESS

    # Cursor
    # How far past a hard edge the tracked position may run while the
    # cursor stays pinned - the head-tracking equivalent of lifting a
    # mouse. Moving back spends the bank before the cursor follows, so the
    # head can return past centre. 0 disables it.
    clutch: float = DEFAULT_CLUTCH

    # Yield to another pointing device. On by default, unlike the clutch and
    # the acceleration curve: this one restores an expectation rather than
    # adding a behaviour, since two things moving one cursor at once is a
    # fight nobody asked for. `yield_delay` is extra hold-off *after* the other
    # device stops, in seconds; 0 resumes on the next frame.
    yield_to_mouse: bool = True
    yield_delay: float = 0.0

    # Control
    hotkey: str = DEFAULT_HOTKEY
    # Open straight to the tray with no window. Off by default: someone who has
    # just installed this needs to see the preview to aim the camera, and a
    # first run with no window at all looks like nothing happened.
    start_minimized: bool = False

    def roi(self) -> tuple[int, int, int, int]:
        """The (x, y, w, h) region searched, always a real box.

        A zero width or height resolves to the whole frame rather than to a
        degenerate box that would reject every blob.
        """
        if self.roi_w > 0 and self.roi_h > 0:
            return (self.roi_x, self.roi_y, self.roi_w, self.roi_h)
        return (0, 0, self.width, self.height)

    def roi_is_whole_frame(self) -> bool:
        """Whether the region covers everything, i.e. excludes nothing."""
        return self.roi() == (0, 0, self.width, self.height)

    def set_roi(self, x: int, y: int, w: int, h: int) -> None:
        """Adopt a region, clamped to the frame so it can never sit outside it."""
        x = max(0, min(int(x), self.width - 1))
        y = max(0, min(int(y), self.height - 1))
        self.roi_x, self.roi_y = x, y
        self.roi_w = max(1, min(int(w), self.width - x))
        self.roi_h = max(1, min(int(h), self.height - y))

    @classmethod
    def load(cls, path: Path | None = None) -> Config:
        """Read the config, falling back to defaults for anything absent."""
        target = path or config_path()
        if not target.exists():
            return cls()

        with target.open(encoding="utf-8") as handle:
            data = json.load(handle)

        known = {field.name for field in fields(cls)}
        unknown = set(data) - known
        if unknown:
            print(f"config: ignoring unknown setting(s): {', '.join(sorted(unknown))}")

        return cls(**{key: value for key, value in data.items() if key in known})

    def save(self, path: Path | None = None) -> Path:
        target = path or config_path()
        target.parent.mkdir(parents=True, exist_ok=True)
        with target.open("w", encoding="utf-8") as handle:
            json.dump(asdict(self), handle, indent=2, sort_keys=True)
            handle.write("\n")
        return target

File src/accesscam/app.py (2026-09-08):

"""The cursor-control pipeline: camera to tracker to smoother to mapper to mouse.

Headless by design at this milestone. There is no window to click on, so the
pause hotkey is the only control - and the whole thing therefore starts paused
and waits to be switched on deliberately.

Run with `python -m accesscam`.
"""

from __future__ import annotations

import argparse
import sys
import time
from pathlib import Path

import cv2

from accesscam import __version__, startup
from accesscam.camera import CameraError, CameraSettings, CameraSource, probe_devices
from accesscam.config import Config, config_path
from accesscam.engine import Engine
from accesscam.hotkeys import create_listener, parse_hotkey
from accesscam.log import log, start_logging
from accesscam.mouse import CursorController, create_backend
from accesscam.mouse.fake import RecordingMouse

BACKENDS = {
    "auto": None,
    "dshow": cv2.CAP_DSHOW,
    "msmf": cv2.CAP_MSMF,
    "v4l2": cv2.CAP_V4L2,
    "any": cv2.CAP_ANY,
}

STATUS_INTERVAL = 2.0


def frozen() -> bool:
    """Whether this is the packaged application rather than a source checkout.

    PyInstaller sets `sys.frozen`. It changes one thing that matters here: who
    is running it, and therefore what they expect to happen when they do.
    """
    return bool(getattr(sys, "frozen", False))


def wants_ui(args) -> bool:
    """Whether to open the settings window.

    A packaged AccessCam opens it unless told not to: someone who double-clicks
    an application expects to see it, and an invisible process that has taken
    over the pointer is alarming rather than tidy. A source checkout keeps the
    opposite default, because `python -m accesscam` is how the pipeline gets
    exercised with no UI in the way.
    """
    if args.headless:
        return False
    return bool(args.ui) or frozen()


def build_camera(config: Config, wait: float = 0.0) -> CameraSource:
    camera = CameraSource(
        CameraSettings(
            device=config.device,
            width=config.width,
            height=config.height,
            fps=config.fps,
            backend=BACKENDS.get(config.backend),
        )
    )
    camera.open(wait=wait)
    camera.set_exposure(config.exposure)
    return camera


def list_devices(max_index: int = 8) -> int:
    """Probe camera indices and report enough to tell them apart.

    The index differs from machine to machine, and a laptop's built-in webcam
    frequently takes 0. The Arducam is distinguishable by granting 1920x1080,
    which lower-resolution webcams will not.
    """
    print("probing camera indices (this takes a few seconds)...\n")
    print(f"  {'idx':>3s}  {'granted at 1920x1080':>20s}  {'codec':>5s}   likely")
    found = probe_devices(max_index)
    for device in found:
        guess = "Arducam" if device.likely_arducam else "other webcam"
        size = f"{device.width}x{device.height}"
        print(f"  {device.index:3d}  {size:>20s}  {device.codec:>5s}   {guess}")

    if not found:
        print("  no readable cameras found - check the USB connection")
        return 1
    print("\nSet the one you want with:  python -m accesscam --device N --write-config")
    return 0


def register_task() -> int:
    """Register the elevated startup task, for a caller with no window to click.

    The installer runs this rather than composing a `schtasks` command line of
    its own, so that what the task runs is defined in exactly one place. Two
    definitions would drift, and the drift would be invisible until it was
    confusing: the Application tab compares the registered command against
    `startup.executable()`, and would start calling a perfectly good task
    stale because the installer quoted it differently.
    """
    outcome = startup.enable()
    if outcome.ok:
        log.info("registered the startup task: %s", startup.executable())
        print("Registered the AccessCam startup task.")
        return 0

    log.error("could not register the startup task: %s", outcome.message)
    print(f"error: {outcome.message}", file=sys.stderr)
    return 1


def warn_if_not_elevated() -> None:
    """Say so up front when hovering will not register on privileged windows.

    UIPI silently drops input from a medium-integrity process to a higher
    one. The cursor still moves, so nothing looks broken - the symptom is
    only that hover-driven UI stops responding, which is very hard to
    attribute without being told.
    """
    if sys.platform != "win32":
        return
    from accesscam.mouse.windows import is_elevated

    if not is_elevated():
        print("  note: not running as administrator. The cursor will move, but")
        print("        windows at higher privilege will not see it hover, so")
        print("        on-screen keyboards stop highlighting and UAC prompts")
        print("        ignore it. Relaunch from an Administrator terminal.")
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

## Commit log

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2026-08-09 Add M1 camera bring-up: capture, dot tracking, and diagnostics
    CameraSource forces MJPEG and manual exposure, and reports the frame rate
    actually delivered rather than the advertised one. DotTracker thresholds
    the frame and returns an intensity-weighted sub-pixel centroid, preferring
    continuity with the previous frame so a bright lamp cannot steal the track.
    tools/camera_bringup.py drives both with a live overlay and measures the
    travel range and jitter that will set the app's default gains and smoothing.
    Backend testing on Windows found MSMF silently clamps exposure at -6 while
    DirectShow applies the full range; the tool now surfaces the driver-reported
    value and offers --backend to compa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
    [camera.py, tracker.py]
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2026-08-09 Update housing parts and assembly for reprint
    Adjust fits after the first test print came out tighter than modeled.
    [CameraHousing.SLDPRT, CameraHousing.STEP, CameraHousing.STL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]
2026-08-09 Add MonitorMountBase part and scope the production housing
    Adds the monitor-top mount base that carries the camera housing, plus
    the docs needed to read it correctly.
    The part is a replica of the SmartNav's own monitor base. Reusing that
    base directly was the original plan, but the SmartNav stays connected as
    a working fallback while AccessCam is built, so it could not be
    cannibalised. The only reference available was the original's STL, which
    was authored in inches - so this part is modelled in inches (2.000 x
    1.550 x 1.400in = 50.80 x 39.37 x 35.56mm, 0.150in walls) while the rest
    of hardware/ is metric. Its STEP declares CONVERSION_BASED_UNIT('INCH')
    and the geometry is physically correc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
    [MonitorMountBase.SLDPRT, MonitorMountBase.STEP, MonitorMountBase.STL]
2026-08-10 Update housing and mount models for the next print
    Revises all three parts after fitting the current printed housing. Both
    housing halves grow 2mm taller, 18.80 -> 20.80mm, moving together so the
    mating faces still line up; X and Y are unchanged at 44.60 wide.
    MonitorMountBase keeps its 50.80 x 39.37 x 35.56mm envelope but gains
    internal detail (176 -> 280 triangles).
    HousingBottom picks up real curvature - 12 B-spline, 4 toroidal and 12
    cylindrical surfaces against 11 planes - which is why its mesh goes from
    236 to 2068 triangles and 11KB to 103KB. That is tessellation of genuine
    geometry rather than an over-fine export tolerance, and it stays far
    under the size ceiling in hardware/README.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
    [CameraHousing.SLDPRT, CameraHousing.STEP, CameraHousing.STL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]
2026-08-10 Fix MJPEG negotiation on the Arducam and record M1 bring-up results
    First real run against the Arducam surfaced a FOURCC ordering bug that
    was halving the frame rate. camera.py set CAP_PROP_FOURCC before the
    frame size, with a comment asserting that was required to avoid a YUY2
    fallback. On this camera it is exactly backwards - that order causes the
    fallback:
    FOURCC before size YUY2, 14.8fps @640x480, 10.0fps @720p
    FOURCC after size MJPG, 29.3fps at both
    FOURCC before and after YUY2, same as before-only
    So the early call is what poisons the negotiation. Setting it only after
    the size fixes it, verified through CameraSource: 640x480 MJPG at 29.2fps
    with exposure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
    [camera.py]
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2026-08-10 Reject bright distractors by shape and brightness, not size
    The 2026-08-10 daylight bring-up run reported 1.2 x 3.2px of marker
    travel with the dot still "found": the signature of a track locked onto
    something stationary. Selection was the cause. _select picked the
    largest blob on acquisition, and in a lit room the largest bright thing
    is rarely the marker - so it grabbed a sunlit object on the first frame,
    after which max_jump did its job faithfully and defended the wrong
    target, leaving the real dot permanently outside the 120px window.
    Two filters address it:
    Shape - candidates must have circularity (4*pi*A/P^2) of at least 0.5.
    Measured on test shapes, the marker comes in at 0.81 and a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
    [tracker.py]
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2026-08-10 Add One Euro smoothing
    Third piece of M2. A fixed low-pass cannot win here: enough smoothing to
    settle the cursor at rest adds enough lag to make fast movement feel like
    dragging. One Euro varies its cutoff with speed instead - calm when
    nearly still, progressively more responsive as the marker moves.
    Filters the marker position in camera pixels, upstream of the mapper's
    gain. Filtering after the gain would make the cutoffs gain-dependent, so
    changing a gain would mean retuning the filter; in camera pixels the
    tuning holds regardless.
    Defaults were tuned by replaying the measured M1 signal through the full
    smoother/mapper/cursor chain at 31px/px rather than guessed. Against
    unfiltered inpu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
    [smoothing.py]
2026-08-10 Wire up the cursor pipeline: config, app entry point, setup guide
    M2's remaining pieces. `python -m accesscam` now drives the cursor from
    head movement: camera -> tracker -> One Euro -> mapper -> SendInput, with
    F9 as the pause control.
    config.py stores everything tunable as JSON in %APPDATA%\AccessCam. Each
    default is imported from the module that owns it, so there is one place
    to change any value. Unknown keys are reported and ignored rather than
    being fatal - being locked out by your own settings file is a bad failure
    for a tool someone relies on to use their computer - and a partial file
    fills in the rest from defaults, so a value can be edited by hand without
    restating everything.
    app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
    [app.py, config.py]
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2026-08-10 Hold the cursor at monitor boundaries so they work as clutch points
    Reported from the first real session: SmartNav and the QuadStick stop the
    cursor at the boundary between two displays, and John uses those stops
    deliberately - the cursor parks while he moves his head back to a
    comfortable position. AccessCam slid straight through, so that clutch
    disappeared.
    This is an ergonomic mechanism rather than a cosmetic difference. A
    head-tracked cursor has no equivalent of lifting a mouse, so the places
    it can be parked are the places a long traverse can be broken up. Losing
    them means finishing every far reach in whatever posture the movement
    required.
    CursorController now accumulates pressure a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
    [app.py, config.py]
2026-08-10 Replace edge resistance with an opt-in clutch, off by default
    The edge resistance added in 2ae82b0 was the wrong mechanism. John's
    clutch is not about being stopped at a boundary: it is pushing the cursor
    into an edge, banking travel past it, then moving the head back - often
    past centre - while the cursor stays pinned. That re-biases where the
    head sits relative to the screen, which is the head-tracking equivalent
    of lifting a mouse. Resistance at boundaries does not do that, and firing
    at every point along every boundary was disliked besides.
    CursorController now separates the tracked position from the cursor
    position. The tracked position may run up to `clutch` pixels past a hard
    edge wh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
    [app.py, config.py]
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2026-08-14 Ignore bright objects outside a region of interest
    Daylit windows at the frame edges image as bright as the retroreflective
    marker, and once one wins acquisition max_jump defends it - the same
    failure mode as the 2026-08-10 daylight run, but from a source the shape
    and brightness filters cannot reject, since a window is neither dim nor
    elongated.
    The blunt fix works because the geometry is stable: the user sits in the
    middle of frame and the offenders are at the edges. A configured box
    around the user excludes them outright, so no amount of exposure or
    threshold tuning has to separate them.
    Off by default (all-zero box means the whole frame), because a fixed box
    is only correct while the u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
    [app.py, config.py, tracker.py]
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2026-08-15 Scale gain with marker speed so precision and reach stop competing
    Four days of full-day use surfaced fatigue from jitter at slow speeds, with
    holding a caret still for text selection as the hard case. The smoother is
    already at its floor - below a min_cutoff of 0.3 the resting excursion stops
    improving while lag keeps growing - so the ~4.2px that remains is not noise
    the filter can still reach. What amplifies it is the flat gain, which has to
    serve both crossing a 7680px desktop and landing between two characters.
    A Hill curve scales gain from accel_floor at rest up towards full as the
    marker speeds up. Unlike a dead zone it damps slow movement rather than
    discarding it, which is exactly t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
    [app.py, config.py, mapper.py]
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2026-08-15 Add the settings window: two tabs, live preview and the accel curve
    Two tabs, split by the question being asked. "Camera & marker" answers whether
    the dot is being seen and holds everything that changes what the tracker gets.
    "Cursor movement" answers whether the cursor feels right and holds everything
    downstream of finding the dot. Mixing them is how you end up adjusting gain to
    fix an exposure problem.
    The window stays usable while the cursor is live, as the SmartNav's does. That
    is the whole point rather than a detail: the reason to open it is usually that
    the cursor is misbehaving, so a window needing a well-behaved cursor would be
    useless exactly when it is wanted. Every value is there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
    [app.py, controls.py, curve.py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]
2026-08-16 Make the region of interest always live, and draggable on the preview
    The region had a disabled state: all four values zero meant "search the whole
    frame", and any other value meant a box. That is two behaviours wearing one
    setting, and it showed up the moment the window drew it - the overlay simply
    was not there, with nothing to say whether that meant no region or a broken
    one.
    There is no disabled state now. The region is always in force and a zero
    dimension resolves to the whole frame, so the preview always has a box to show
    and to drag, rather than one appearing from nowhere. The startup line still
    only mentions it when it is not the whole frame, since that is the case worth
    reporting.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
    [app.py, config.py, main_window.py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]
2026-08-16 Give the region corner handles instead of four sliders
    Four sliders for a rectangle was the wrong instrument. A region is a place, not
    four quantities, and splitting it across Left/Top/Width/Height meant reading
    coordinates off a picture and typing them back in - the job the picture should
    have been doing. They also took most of the tab's vertical space for something
    set once.
    Corner handles now, with the usual crop-tool behaviour: a corner resizes
    against its opposite, dragging inside moves the box, dragging outside draws a
    new one. The four sliders are replaced by a one-line readout of the box and how
    much of the frame it leaves searched, which is the part that was actually worth
    reading.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
    [main_window.py, preview.py]
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2026-08-16 Double the preview to a quarter of the monitor height
    An eighth put it at 240x180, which was too small to grab the region's corner
    handles with a head-tracked cursor. The share is now a named constant rather
    than a divisor buried in the sizing call, since it has already been retuned
    once.
    [main_window.py]
2026-08-16 Fix the slider track: one blue bar, not two with a gap
    The track rendered as two light bars sandwiching a dark strip. That was a
    malformed selector rather than a design choice: `QSlider:focus::handle:horizontal`
    puts the pseudo-state before the sub-control, which Qt mis-parses and applies to
    the whole slider, painting the widget full height with the handle focus colour.
    The 4px groove then sat in the middle of it looking like a gap.
    Pseudo-states go after the sub-control - `::handle:horizontal:focus` - and there
    is now a comment saying so, because the wrong form fails silently and looks
    deliberate.
    With that gone the track is a single 4px bar, now blue with a near-white handle
    so the value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
    [main_window.py]
2026-08-16 Put the acceleration controls under the curve they draw
    The three values that shape the curve sat across the page from the plot of it,
    so tuning meant looking in one place while changing something in another. They
    now live inside the plot card, directly beneath it. The right column keeps the
    settings the plot says nothing about: gains, smoothing and the clutch.
    The note under the plot is gone. It restated in words what the curve already
    showed, and the live marker riding the curve says it better.
    Two defects fixed while in here. The live readout ran off the right edge of the
    plot at full speed - the one place the number is most worth reading - and now
    flips to the left of its line instead.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
    [curve.py, main_window.py]
2026-08-16 Card the movement tab right column to match the left
    The curve and its controls sat in a card while the gains, smoothing and clutch
    sat on bare background, which made the tab read as one panel and some loose
    parts rather than two groups.
    The card hugs its content with the spare height below it rather than inside it,
    so both columns end at the same kind of edge instead of one stretching to the
    bottom of the tab.
    [main_window.py]
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2026-08-16 Match the card heights, centre the preview, fix the window size
    The cards hugged their content, so the two on a tab ended at different heights
    depending on how much happened to be in each. They now stretch to fill the tab
    and carry their spare height inside, below the content, which matches them by
    construction rather than by coincidence. The preview sits centred in whatever
    height its card ends up with, opposite the middle of the controls rather than
    clinging to the heading.
    The window is fixed at the size its content needs - 840x659 on this machine.
    Everything is visible at that size on both tabs, so resizing could only add
    empty space. It also means the controls never move between sessio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
    [main_window.py]
2026-08-16 Normalise the curve's vertical axis to a percentage of full gain
    The axis was absolute px/px taken from h_gain, which made it wrong twice over.
    It showed a number only true for the horizontal axis, while the same curve
    scales v_gain as well - and it redrew itself every time a gain slider moved,
    even though the curve's shape had not changed at all.
    It is now 0-100% of full gain, so one plot is honest about both axes and only
    the three acceleration values redraw it. The precision floor also becomes
    directly readable: a floor of 0.35 starts the curve at 35%, where before it
    started at whatever 0.35 x h_gain happened to be.
    The vertical axis is labelled now too. It had no title at all, which i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
    [curve.py, main_window.py]
2026-08-16 Size the plot text, the step buttons and the columns
    Four adjustments from John.
    The plot drew its labels a point smaller than everything else, which made the
    axes read as a footnote to the settings rather than as one of them. It now uses
    the widget's own font, matching the setting titles beside it, with the margins
    opened up to suit.
    Step buttons drop to 80% of their box with the glyph left at its old size, so
    what shrinks is the padding rather than the thing being aimed at.
    Both left cards now take the preview's width, so the curve sits over exactly
    the ground the preview does and switching tabs no longer shifts everything
    sideways.
    Both right cards take 135% of the width their content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
    [controls.py, curve.py, main_window.py]
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2026-08-16 Reserve the status bar's height before fixing the window size
    QMainWindow builds its status bar on demand, so the first "Saved" or
    "Searching the whole frame again" created it after the window size had already
    been fixed. The height it needed came out of the central widget, so the cards
    visibly shrank the first time a message appeared and never grew back.
    It is now built during setup, before the size is measured, so the room is
    reserved from the start: the window is 21px taller and nothing moves when a
    message comes and goes. The size grip is off, since there is nothing to grip on
    a fixed window.
    [main_window.py]
2026-08-16 Add an Application tab: camera choice, startup options, quit
    A third category rather than a drawer for leftovers. The other two tabs answer
    "is the dot being seen" and "does the cursor feel right", and none of this
    answers either - the camera choice in particular belonged nowhere, since it is
    not a tracking-quality setting but which hardware to point at. It was also the
    one gap stopping anyone else installing this: a new machine could not pick its
    camera without hand-editing JSON.
    Switching cameras cannot be live. `Engine.use_camera` refuses to run while the
    loop is going, because the capture has to be closed and reopened and the loop
    cannot read from a camera being swapped underneath it. I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
    [app.py, camera.py, engine.py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]
2026-08-16 Register the logon task against pythonw, and notice a stale one
    The task ran python.exe, which is a console application - so Windows allocated
    a console window for it, and a black box would appear behind the settings
    window at every single logon, for a program that has a GUI and never prints to
    it. pythonw.exe is preferred now where both exist.
    That change would have been invisible to anyone who had already ticked the box:
    a registered task keeps whatever command it was created with, so it would have
    gone on running the old one while the checkbox read "on". The tab now reads
    back what is actually registered and says so when it does not match, with the
    fix (untick, re-tick, elevated).
    Colla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
    [main_window.py, startup.py]
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2026-08-16 Wait for the camera at logon instead of giving up
    The logon task fired correctly on restart, ran, and exited 1 - so the tray
    icon never appeared and nothing anywhere said why. The trigger fires the
    moment the desktop is up, which beats a USB camera's enumeration: opening
    device 1 failed, launch() returned before it had built a window or a tray,
    and pythonw has no console to print the reason to.
    So `open()` can now be told to keep trying for a while, and the registered
    logon command asks for a minute of it. A terminal launch still fails at
    once, because someone who mistyped the device index wants telling now.
    Failing is also no longer silent. QApplication is now created before the
    camera ra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
    [app.py, camera.py, main_window.py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]
2026-08-16 Give the logon start somewhere to speak, and wait for the tray
    Two reboots have now ended with no tray icon and no explanation. Under
    pythonw there is no console: print goes nowhere, an unhandled exception
    disappears with the process, and the only evidence is LastTaskResult = 1 -
    which is Python's exit code for every failure and so names none of them.
    A log now opens as the first thing main() does, beside config.json, and
    sys.excepthook and threading.excepthook write into it, so the next silent
    death arrives with a traceback attached. Each startup step says it got that
    far, and the camera reports which attempt succeeded - the only way to tell a
    generous --wait-for-camera from a lucky one.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
    [app.py, camera.py, log.py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]
2026-08-16 Offer the cameras that are there instead of ending the launch
    A first run on a machine that has never seen AccessCam nearly always has the
    wrong camera number: device defaults to 0, a built-in webcam habitually takes
    0, and the IR camera turns up at 1 or later. That produced "Could not open
    camera device 0", an OK button, and no way past it - for an application whose
    whole job is to hand someone a working pointer.
    The picker already existed, in the Application tab, behind a successful start.
    Failing to open the camera now puts the same list in front of one: what
    answered, which one is likely the Arducam (it is the one granting 1920x1080),
    Scan again for a camera plugged in after the dialog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
    [ELP_Camera.SLDPRT, ELP_Camera.STEP, ELP_Camera.STL]
2026-08-16 Add the ELP camera model, for a camera not yet chosen
    A second candidate to the Arducam B0205, modelled for fitting work on the
    production housing. Part, STEP and STL together, so the housing can be built
    against it without SolidWorks and so anyone printing has the mesh.
    Supersedes the partial export that an unrelated commit swept in an hour
    earlier: 612 triangles against 174.
    Checked before committing rather than after, per the STL that went in wrong
    once already - 612 triangles, no degenerate facets, no zero-length normals,
    bounding box 40 x 46 x 45. Millimetres, which is what M3 wants the production
    housing rebuilt in; only MonitorMountBase carries inches, and deliberately.
    Co-Authored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
    [ELP_Camera.SLDPRT, ELP_Camera.STEP, ELP_Camera.STL]
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2026-08-18 M4.1: say in the window when there are no administrator rights
    warn_if_not_elevated() was called once, inside the headless run(), where it
    prints to a console. A packaged app has none, so the UI has never mentioned
    elevation at all - and this is the failure that looks least like a failure: the
    cursor moves, because the cursor is global, while every higher-integrity window
    ignores the pointer hovering over it. On-screen keyboards stop highlighting and
    nothing anywhere says why.
    A standing banner rather than a dialog, because a dialog is dismissed in the
    first minute and the symptom is met an hour later with no way to connect the
    two. It carries a Restart as administrator button that hands ov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
    [main_window.py, startup.py]
2026-08-18 M4.2: one AccessCam at a time, and the second fetches the first
    A camera cannot be opened twice. Launching a second copy - double-clicking the
    shortcut again, or starting one by hand when the logon task already did - waited
    out --wait-for-camera for a camera the first copy held and then reported it as a
    hardware fault. Under the logon task, with pythonw and no console, it said
    nothing at all and simply never appeared.
    Exiting quietly would fix the misleading error and leave a worse one: the user
    asked for AccessCam and nothing happened. So the second copy posts a registered
    window message and the first surfaces its window. Clicking a shortcut twice
    means "show me AccessCam", not "run two of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
    [main_window.py, single_instance.py, tray.py]
2026-08-18 M4.7: one version, said out loud
    __version__ existed in __init__.py, was surfaced nowhere, and was duplicated in
    pyproject.toml where the two could quietly disagree. pyproject now reads it from
    the package, so the command line, the window title and the built artifact cannot
    claim different versions of the same program.
    --version prints it, the window title carries it, and every log run opens with
    it - a bug report against "AccessCam" with no version is nearly useless, and the
    log is the thing a user will actually be asked to send.
    Also marks M4.1, M4.2 and M4.7 done in the plan.
    [app.py, main_window.py]
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
